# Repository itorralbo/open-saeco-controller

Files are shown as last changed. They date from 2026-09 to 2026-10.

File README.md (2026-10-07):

# Open Saeco Controller

Controladora open-source para sustituir la electrónica de la Saeco Incanto HD8911,
placa objetivo 421941308981/01. Proyecto independiente, sin afiliación a Philips/Saeco.

**Rev A: diseño en curso, sin hardware fabricado ni ensayado. Hay 230 VAC. Toda
etapa de potencia es experimental hasta verificación. El firmware actual no
controla cargas.**

## Objetivo
Controlar la máquina sin depender de la electrónica original, inicialmente por USB/web.
Conservar mecánica y cableado solo tras verificar compatibilidad. Se diseñará un frontal
nuevo que reproduzca la posición de los botones y use una pantalla reemplazable.
STM32 se ocupará del control; ESP32, de interfaz y comunicaciones.

## Documentación
- [Arquitectura](docs/architecture.md)
- [Reverse engineering HD8911](docs/HD8911/README.md)
- [Plan de caracterización de la cafetera](docs/HD8911/characterization-plan.md)
- [Mapa I/O preliminar](docs/io-map.md)
- [Diseño preliminar del frontal y pantalla](hardware/front-panel/README.md)
- [Subsistema display y UI (ST7789 + LVGL)](docs/display-ui.md)
- [Decisión de frontal/display (ADR-0001)](docs/adr/0001-front-panel-display-st7789.md)
- [Diseño de la principal](hardware/controller/core-design.md) y
  [su colocación y ruteo](hardware/controller/layout.md)
- [Arquitectura de potencia](hardware/power/power-architecture.md)
- [Abrir y editar los proyectos KiCad](hardware/kicad-workflow.md)
- [Componentes y fabricación JLCPCB](hardware/assembly/README.md)
- [Seguridad](docs/safety.md)
- [Roadmap y validación](docs/roadmap.md)
- [Licencias y fuentes](docs/licensing.md)

## Estructura
```
docs/                 arquitectura, seguridad, ingeniería inversa de la HD8911 y registro de verificación
hardware/controller/  principal completa: esquema, PCB de cuatro capas ruteada, BOM; no fabricable
hardware/front-panel/ frontal: esquema, PCB ruteada y paquete JLCPCB candidato, sin pedir
hardware/assembly/    catálogo de componentes con códigos JLC y stock observado
hardware/power/       diseño de las etapas de red, 24 V, válvula y watchdog
firmware/stm32/       núcleo C portable, sin BSP ni pines
firmware/esp32/       proyecto mínimo ESP-IDF
firmware/common/      contrato de comunicaciones propuesto
recipes/              ejemplo de simulación no ejecutable
sim/                  modelo de las dos placas para el simulador del firmware
tools/                generadores, layout, ruteo y comprobaciones de las dos placas
tests/                pruebas de bloqueo del núcleo
```

## Verificación local
Con Python 3: `python tools/check_scaffold.py`.
Conexiones del frontal: `python tools/check_front_panel.py` (no sustituye ERC).
Núcleo y suministro: `python tools/check_controller_core.py` (no sustituye ERC/DRC).
ERC y netlist nativos, con KiCad 10: `python3 tools/validate_kicad.py`.
Geometría de la PCB principal (condensadores de entrada de los bucks), con el
Python de KiCad desde `tools/`: `check_controller_pcb.py --self-test`.
Coherencia firmware ↔ placas: `python tools/build_board_model.py --check`
([simulador](sim/README.md), [informe](sim/board-report.md)).
Con CMake >= 3.20 y compilador C:
```
cmake -S firmware/stm32 -B build/host
cmake --build build/host --config Debug
ctest --test-dir build/host -C Debug --output-on-failure
```
El build host no produce firmware STM32 flasheable. USB/web, drivers, protocolos y
calibraciones aún no están implementados. Todos los pinouts y niveles eléctricos
sin evidencia permanecen TBD.

El material original de esta base se publica bajo [MIT](LICENSE). Referencias y
materiales de terceros conservan sus derechos; no se redistribuyen en este paquete.

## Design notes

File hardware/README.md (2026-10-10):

# Hardware

- [Frontal](front-panel/README.md): botones, LED y conector de pantalla, con la
  mecánica recuperada de la placa original. PCB ruteada, DRC limpio y paquete
  JLCPCB candidato, pendiente de las comprobaciones previas al pedido.
- [Principal](controller/core-design.md): lógica, USB de servicio, sensores,
  cargas de 24 V y de red y fuente aislada en una sola placa de cuatro capas,
  ruteada y con DRC limpio. [Contrato con el frontal](controller/front-panel-interface.md).
- [Potencia](power/README.md): etapas de red, válvula y watchdog.
- [Selección para montaje JLCPCB](assembly/README.md) y
  [proyectos KiCad](kicad-workflow.md).

La principal no es fabricable: faltan la comprobación 1:1 de conectores y su
acoplamiento con los mazos, y la revisión independiente de aislamiento y
seguridad. Su paquete JLCPCB es candidato: no pedirlo hasta
cerrarlos.

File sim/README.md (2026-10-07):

# Simulador de la cafetera

Entorno para probar el firmware sin hardware, coherente con las dos PCBs: el
cableado del simulador no se escribe a mano, se genera a partir de los netlists
de KiCad, así que un error de diseño aparece como un fallo de simulación.

| Fase | Contenido | Estado |
|---|---|---|
| F0 | Modelo de las dos placas, contrato de firmware, comprobaciones y `board_pins.h` | Hecha |
| F1 | STM32 en host contra la placa virtual: HAL, modelos de componentes y planta | Hecha; planta con valores supuestos |
| F2 | ESP32 en host: ST7789 y TCA9534 virtuales, protocolo v0 | Hecha; LVGL queda para el puerto ESP-IDF |
| F3 | Panel web local: frontal, pantalla, gráficas, inyección de fallos, VCD | Hecha |
| F4 | Menús y puesta a punto: pruebas de cargas y medidas, cafetera visual en el panel | Hecha; tiempos y corrientes de la planta supuestos |
| F5 | Recetas y máquina de estados completa | Pendiente |

## Entorno (macOS, Windows y Linux)

Hace falta Python 3.10 o posterior (CI usa 3.12). El código del simulador solo
usa la biblioteca estándar; lo único externo es un compilador de C para los dos
firmwares, y [`requirements.txt`](requirements.txt) lo trae con pip (`zig cc`,
paquete `ziglang`): no hacen falta Xcode, MinGW ni Visual Studio.

macOS / Linux:
```
python3 sim/setup_env.py
source .venv/bin/activate
```

Windows (PowerShell):
```
py sim\setup_env.py
.venv\Scripts\Activate.ps1
```

Si PowerShell no deja ejecutar `Activate.ps1`, basta con llamar a
`.venv\Scripts\python` en lugar de `python`.

[`setup_env.py`](setup_env.py) crea `.venv` en la raíz del repositorio, instala
los requisitos, copia [`.env.example`](.env.example) a `sim/.env` si no existe
y compila los dos firmwares para comprobar la cadena. Con el entorno activado,
los comandos de abajo funcionan igual en los tres sistemas.

`sim/.env` (ignorado por git) guarda lo propio de cada máquina, por ejemplo
otro compilador (`CC`) o el SDK de macOS (`SDKROOT`) para un compilador del
sistema; las variables ya definidas en la terminal mandan. Sin `CC`, el
simulador usa `zig cc` si está instalado y si no `cc`, `gcc` o `clang`. CI
pasa los escenarios en Windows y macOS con este entorno, y en Linux con el
`cc` del sistema.

## F0: modelo de placa

```
python tools/build_board_model.py           # regenera las salidas
python tools/build_board_model.py --check   # falla con errores de diseño o salidas viejas
python tools/build_board_model.py --as-if-fixed
python -m unittest discover -s tests/sim
```

`--as-if-fixed` repite las comprobaciones como si cada símbolo siguiera ya su
pinout de referencia: muestra lo que seguiría mal tras corregir los símbolos.
Los netlists se leen de `hardware/*/validation/netlist.xml`; tras editar un
esquema hay que regenerarlos con `tools/validate_kicad.py`.

Entradas:
- [Contrato de firmware](../firmware/common/signals.json): cada señal que usa el
  firmware (red, función, nivel activo, nivel en reset, a qué conector debe
  llegar y si va enclavada por el watchdog), el mazo entre placas, los rails y
  el teclado.
- [Pinouts de referencia](reference/pinouts.json) de cada CI activo, transcritos
  del fabricante con la fuente anotada.
- [Capacidades de los MCU](reference/mcus.json): funciones alternativas, canales
  ADC, pines reservados y estado tras reset. Un pin sin fila falla hasta que se
  añade desde la fuente.
- [Límites eléctricos](reference/devices.json) de cada CI y transistor (F1),
  con la hoja de datos de cada uno: VIH/VIL, VOH, VGS a la que se especifica
  RDS(on), IFT del opto, tensión de cierre del relé y tiempos del TPS3828.

Salidas (generadas, no editar):
- [Informe](board-report.md) con hallazgos, tabla de señales y entradas analógicas.
- `board-model.json`: componentes, redes globales y señales resueltas; es la
  entrada del simulador de F1.
- `firmware/stm32/include/board_pins.h` y `firmware/esp32/main/board_pins.h`:
  puerto, pin, AF y canal ADC de cada señal según los pads físicos.

## Qué comprueba

| Regla | Qué detecta |
|---|---|
| `symbol-pinout` | Símbolo cuyos pads no coinciden con el pinout del fabricante |
| `supply-pad`, `ground-pad`, `output-on-rail` | Alimentación o masa del CI real en una red de señal, o una salida unida a un rail |
| `pin-shift`, `signal-pad` | Señal que en el componente real cae en otro pin o en un pad de alimentación |
| `pin-caps`, `reserved-pin`, `strapping-pin` | Pin sin el periférico pedido (AF, ADC, USB) o reservado (SWD, BOOT0, flash/PSRAM) |
| `signal-path` | Orden que no llega a su carga o entrada que no viene de su conector, atravesando resistencias, puertas, drivers, optos, triacs, relé y mazo |
| `interlock` | Orden de carga que no pasa por una AND con `STM_NRST` (watchdog) |
| `reset-level` | Nivel de cada orden con el MCU en reset (pines en alta impedancia, pull internos de depuración) |
| `pull` | Entrada sin el pull-up o pull-down que requiere |
| `analog` | Divisores, NTC (ventana y °C/LSB) y límite de corriente del DRV8876 resueltos por análisis nodal |
| `harness` | Pines del mazo J104 ↔ J1 con redes distintas a cada lado |
| `keypad` | Dirección I²C del TCA9534, bus, mapa bit → tecla y LED |
| `uart-pair`, `unclaimed-net`, `power-domain` | TX con RX, redes del MCU que el firmware no usa, pull-ups en otro dominio |
| `drive` | Orden que no mueve su carga en el peor caso: activa, inactiva, con el MCU en reset y, si va enclavada, con `STM_NRST` bajo y el pin aún activo, con los rails al mínimo y al máximo |
| `drive-current` | Salida del MCU o de una puerta que entrega más corriente de la que garantiza su VOH/VOL |
| `drive-limit` | IF del opto, tensión de bobina o VDS por encima del máximo |
| `slow-edge` | Entrada lógica sin histéresis en una red RC más lenta que su Δt/Δv máximo |
| `back-feed` | Entrada de alimentación externa que llega al nodo de conmutación de un buck por bobinas o fusibles, sin cruzar otro rail |
| `reverse-polarity` | Entrada de banco cableada a mano (`external_supplies.unkeyed`) que, con el cable invertido, llega por fusibles o bobinas a algo distinto de un diodo serie, un TVS a masa, resistencias, condensadores no polarizados, una bobina de relé o conectores |
| `probe-header` | Cabecera de medida (`probe_headers`) con dos tensiones distintas en pines contiguos o un pin de raíl sin resistencia serie de al menos `min_ohms` |
| `offboard-supply` | Alimentación que sale de la placa por un mazo (`offboard_supplies`) sin un interruptor con límite de corriente ni una resistencia serie de al menos `min_ohms` |
| `tvs` | TVS que conduciría con el rail en su máximo (VWM) o que no empieza a conducir (VBR máx.) antes del máximo absoluto de lo que protege |
| `resistor-power` | Resistencia que disipa más de su potencia nominal (catálogo o tamaño de huella) en el peor estado; aviso por encima del 60 % |
| `wdi-reset` | Supervisor que enclava RESET ante un pulso en WDI (TPS382x sin A) cuyo WDI cambia, con RESET activo, según PB4 esté en alto, en bajo o liberado |
| `pin-voltage` | Pin de un MCU por encima de su máximo absoluto en algún estado, con los rails y VBUS al máximo |
| `input-level` | Entrada digital activa a cero que, con su contacto cerrado (50 Ω) o abierto, no pasa de VIL o VIH en las dos esquinas |

El modelo usa los pads físicos: cuando un símbolo no sigue su pinout de
referencia, el modelo se comporta como la placa que se fabricaría, no como el
dibujo. Representa el flujo de control y la red en continua por conmutación, no
transitorios, la red de 230 V más allá de quién tiene fase, ni la PWM más allá de
su nivel; no sustituye a ERC, DRC, ni a ensayos de integridad de señal, EMI o
aislamiento.

Las [pruebas de mutación](../tests/sim/test_board_model.py) parten de los
netlists con los símbolos corregidos, rompen una cosa cada vez y exigen que la
regla correspondiente la detecte.

## F1: placa virtual y firmware en host

```
python -m unittest discover -s tests/sim    # F0, F1 y escenarios del firmware
```

- [`circuit.py`](osc_sim/circuit.py): modelo DC por conmutación de las dos
  placas sacado de los netlists. Resistencias, salidas como fuentes de Thevenin,
  LED como caída directa, canales MOSFET como RDS(on), relé por la tensión de
  bobina y triacs por el opto que los dispara. Solo se fía de los puntos que
  garantiza el fabricante; entre ellos el dispositivo queda indefinido y todo lo
  que alimenta también. Cada punto se resuelve dos veces (indefinidos abiertos y
  cerrados) y solo es definido si ambas coinciden.
- [`drive.py`](osc_sim/drive.py): la regla `drive` y la tabla de márgenes del
  [informe](board-report.md). Las esquinas de los rails y las cargas de prueba
  están en el contrato (`rail_range`, `loads`, `drive` de cada orden).
- [`firmware.py`](osc_sim/firmware.py): compila `firmware/stm32` (controlador,
  BSP y bucle principal) con [`hal/hal_sim.c`](hal/hal_sim.c) como biblioteca y
  la carga con ctypes. Usa `$CC` (por defecto `cc`) y `$SDKROOT` si está
  definido; en macOS con las Command Line Tools rotas, el `clang` de Xcode.
- [`board.py`](osc_sim/board.py): pasos de 1 ms. Los pines que el firmware
  configura pasan a la red, U601 vigila WDI y gobierna `STM_NRST`, el STM32 se
  resetea y arranca según ese nivel, y los niveles, códigos ADC y flancos vuelven
  al firmware. Tras el reset los pines están en analógico y UCPD1 deja su Rd de
  5,1 kΩ en PB4/PB6 hasta que el BSP lo quita. U601 usa el extremo de cada rango
  que pone a prueba el caso: time-out de 0,9 s para el firmware sano, 2,5 s para
  el colgado, y 300 ms de reset al arrancar.
- [`plant.py`](osc_sim/plant.py): caldera y NTC, bomba y caudalímetro, grupo con
  sus micros, puerta, válvula y sensor de agua en los pines de los conectores.
  Los valores medidos llevan su fuente; los marcados *ASSUMED* (masa térmica,
  caudal, recorrido del grupo, salida de JP22) esperan a la caracterización.

Los [escenarios](../tests/sim/test_f1.py) comprueban el arranque en las dos
esquinas, que el firmware mantiene callado el watchdog, que un núcleo colgado se
resetea, que el interlock corta las órdenes de un núcleo desbocado en el mismo
paso en que U601 baja `STM_NRST`, que olvidar el *dead battery* de UCPD deja
`nFAULT` indefinido, y la caldera/NTC, el grupo/IPROPI y los flancos del
caudalímetro.

## F2: interfaz, frontal y protocolo

- [`firmware.py`](osc_sim/firmware.py) compila también el núcleo del ESP32
  (`firmware/esp32/core`) con [`hal/hal_esp_sim.c`](hal/hal_esp_sim.c). Sus
  pines entran en el circuito como los del STM32; el I²C y el SPI se resuelven
  al momento en Python.
- [`front.py`](osc_sim/front.py): TCA9534 y ST7789V al otro lado del mazo. Solo
  responden con `3V3_UI` presente; el TCA9534 lee cada tecla como la tensión en
  su pin (pulsador, pull-up y serie del netlist), su INT es una bajada en drenador
  abierto sobre el circuito, y la pantalla descodifica CASET/RASET/RAMWR sobre un
  framebuffer de 320 × 240.
- [`board.py`](osc_sim/board.py) lleva los bytes de la UART entre los dos
  firmwares a 115200 baudios, solo con los dos pines configurados y la línea en
  reposo alto en el receptor, y registra `backfeed` si el ESP32 deja en alto una
  línea del frontal con `3V3_UI` apagado.

Los [escenarios](../tests/sim/test_f2.py): arranque y enlace en las dos
esquinas, STATUS con los rails reales, núcleo FAULT si el ESP32 se cuelga,
pantalla de enlace perdido y recuperación si se cuelga el STM32, START rechazado
como respuesta normal, tecla mantenida al arrancar, rebotes, puerta abierta y
CLEAR_FAULT, standby con el LED, teclado colgado recuperado con un ciclo de
`3V3_UI` sin backfeed, y que el detector de backfeed salta con una línea en alto.

## F3: panel web local

```
python tools/sim_panel.py              # http://127.0.0.1:8765/
python tools/sim_panel.py --speed 5 --corner min
```

[`panel.py`](osc_sim/panel.py) ejecuta los dos firmwares en la placa virtual en
tiempo real (o más rápido) y sirve [`panel/index.html`](panel/index.html), sin
dependencias externas y solo en 127.0.0.1:

- Frontal con las siete teclas en su sitio (mantener pulsado = pulsada), el LED
  STBY y la pantalla tal como la pinta el ST7789V virtual.
- Estado del STM32 y del ESP32, enlace, peticiones y respuestas, `3V3_UI`,
  STATUS, cargas, planta y registro de eventos (watchdog, resets, backfeed).
- Gráficas de caldera, rails y grupo.
- Inyección: puerta, grupo, NTC abierto, nFAULT del DRV8876, STM32, ESP32 o
  teclado colgados, ruido en la UART, rails en sus esquinas, nivel del depósito,
  café en la tolva y sensor de agua (forzado o según el depósito);
  pausa, paso de 100 ms, reinicio y velocidad.
- [VCD](osc_sim/vcd.py) de las señales digitales (órdenes del STM32,
  `STM_NRST`, WDI, enlaces, cargas, teclas, estado del núcleo y pantalla), para
  GTKWave, PulseView o Surfer.

API: `GET /api/state`, `/api/history`, `/api/frame` (RGB565 de 320 × 240),
`/api/vcd`; `POST /api/cmd` con `{"cmd": ...}`. Los
[escenarios](../tests/sim/test_f3.py) la recorren en un puerto efímero.

## F4: menús y puesta a punto

- El ESP32 pinta menús de texto ([`ui.c`](../firmware/esp32/core/ui.c)) y el
  STM32 ejecuta las pruebas de [`service.c`](../firmware/stm32/src/service.c)
  ([protocolo](../firmware/common/protocol.md#pruebas-de-puesta-a-punto)).
- La [planta](osc_sim/plant.py) añade depósito (la bomba se queda sin caudal
  vacío y el sensor JP22 sigue el nivel), tolva y molinillo, el estado de cada
  carga y un arranque del motor con constante de tiempo, que da el pico de
  arranque que mide la prueba del grupo.
- El panel dibuja la cafetera: depósito, bomba, caudalímetro, caldera con el
  calentador y el NTC, válvula, tolva y molinillo, grupo con su posición,
  sentido y corriente, puerta, K701 y los tres triacs. Junto a cada carga, dos
  pilotos: la orden del pin del STM32 y la carga realmente alimentada según el
  netlist; una orden sin carga sale discontinua y una carga sin orden, en rojo.
  El informe de la prueba en curso aparece con sus unidades, y el texto de la
  pantalla también como texto.

Qué mide cada prueba y qué no: la placa mide los rails, la corriente del grupo
(IPROPI), la del molinillo (U704), el NTC, el caudalímetro y los finales de
carrera; las corrientes del calentador, la bomba y la válvula necesitan una
pinza en la sesión de [caracterización](../docs/HD8911/characterization-plan.md),
y las pruebas solo fijan el tiempo y la ventana.

Corriente del molinillo (2026-10-06): U704 entra en el modelo de placa como
dispositivo `hall_current` (su entrada es un conductor de 0,7 mΩ en la línea +
de JP8, su salida VS/2 + 100 mV/A) y la comprobación analógica `hall` exige que
JP8 esté en serie con él y que el rango quepa en el ADC. La planta da la
corriente rectificada de 100 Hz del motor: arranque como rotor bloqueado,
marcha con grano, en vacío y bloqueo (valores supuestos), y una cámara que
recibe el molido y que el grupo vacía al volver a reposo; la corriente al
prensar crece con los gramos. El panel la dibuja junto al molinillo, con dos
fallos nuevos: muelas atascadas y conducto tapado.

Los [escenarios](../tests/sim/test_f4.py) recorren los menús y cada prueba
contra la planta: entradas, ciclo del grupo con I0 en 100-300 mA, válvula,
relé y molinillo sin tocar otras cargas, bomba con calibración del
caudalímetro, bomba sin agua (sin caudal), calentador hasta 90 °C con la
sobreoscilación; molinillo con su corriente, tolva que se vacía a mitad,
sin grano desde el principio y muelas bloqueadas; dosis prensada y conducto
tapado; y que se rechazan con la puerta abierta y se abortan con STOP, con
volver, al abrir la puerta y si se cuelga el ESP32, con todas las cargas a
cero.

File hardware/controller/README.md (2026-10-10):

# Controladora principal

[Diseño de la principal en KiCad](core-design.md): STM32G431RBT6 y
ESP32-S3-WROOM-1U-N8R8 con antena externa U.FL, reset, depuración, UART y USB-C
de servicio. La fuente Mean Well IRM-30-24 va en la propia placa; de sus 24 V
salen el buck de 12 V y, tras él, el de 3,3 V y el corte del frontal. Incluye el
acondicionamiento de NTC, caudalímetro, nivel de agua y tres contactos; un
DRV8876 para el motor del grupo y una etapa low-side para la válvula, cada uno
con su fusible; y las etapas de triac de calentador, bomba y molinillo detrás de
un relé general K701. Un TPS3828 supervisa el STM32 y las puertas AND U602–U604
anulan todas las órdenes de carga y el armado del relé mientras hay reset.

223 posiciones: 214 con MPN y código LCSC, de ellas R415 y R416 sin montar
(DNP); C705, R727, C706 y R728, snubbers RC de los triacs, y C708, supresión del
molinillo, sin montar y sin pieza; J115 y J117 (LEOCO, que JLCPCB no tiene) con MPN y sin código; J111 y
J121, puentes de soldadura. Los tres fusibles de red son Littelfuse 215 de
1500 A a 250 VAC (F702, de 2 A, en pinzas 01110501Z; F701, de 12 A, soldado). J105, J106 y J113 (JP13, JP5 y JP3)
son HR A2506WV, JP8 y JP24 LEOCO 3941P03*000 y 5001P020013, JP17 y JP19 TE RAST 5
1971845-3 y -4 y JP1/JP9 lengüetas TE 63824-1, todas identificadas por el
propietario o casadas con sus fotos. Desde el 2026-10-10 también J107 y J108
(JP14 y JP16, HR A2506WV-02P y -08P) y J109 (JP22, JST ZH B3B-ZR).

La PCB es de cuatro capas, JLC04161H-7628, con planos de GND y 3,3 V solo en el
lado SELV, y está [colocada y ruteada](layout.md) en las posiciones de la placa
original: DRC con todas las severidades sin infracciones ni conexiones abiertas.
La barrera red/SELV de 8 mm es una regla del DRC. Detalle del proyecto en
[kicad-workflow.md](../kicad-workflow.md); reglas y apilado en
[manufacturing.md](manufacturing.md), con el [paquete JLCPCB candidato](fabrication/)
(Gerbers, BOM y CPL, sin pedir); arquitectura de potencia en
[power-architecture.md](../power/power-architecture.md); suministro en
[assembly](../assembly/README.md).

El [contrato del frontal](front-panel-interface.md) fija J104 y los GPIO del
ESP32 para pantalla, botones, UART y USB. Dos divisores permiten leer por ADC los
rails de 12 V y 24 V, y J114 permite medirlos en banco, cada raíl entre dos masas y tras 10 kΩ.

**No es fabricable.** Falta comprobar la placa impresa 1:1 contra la original y
los mazos y el acoplamiento de sus cabeceras, medir la emisión conducida,
medir las cargas y pasar una revisión independiente de aislamiento. Nada está
ensayado. No trasladar pines de una placa de desarrollo al arnés sin verificación.

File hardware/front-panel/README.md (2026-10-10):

# Frontal Rev A.0

Decisión del propietario, 2026-09-16: reproducir la PCB frontal para conservar
la disposición de botones y montar una pantalla nueva compatible con el hueco.
Se conserva como objetivo la geometría original. El 2026-09-18 se recuperaron por
fotogrametría contorno, taladros y centros de los siete pulsadores (184 × 54,3 mm);
están aceptadas como línea base del layout y aplicadas a la PCB de trabajo. Ver
[registro mecánico](mechanical.md).

Estado del layout (2026-09-18): **PCB colocada y ruteada, DRC limpio y paquete JLCPCB
candidato**, pendiente de revisión antes de pedir. Ver [layout](layout.md).

## Entregables de esta iteración

- [Esquema KiCad](kicad/front-panel-reva.kicad_sch), con símbolos embebidos.
- [Proyecto KiCad](kicad/front-panel-reva.kicad_pro) y
  [PCB](kicad/front-panel-reva.kicad_pcb) colocada y ruteada, con huella propia de
  los pulsadores en [OpenSaeco.pretty](kicad/OpenSaeco.pretty/).
- [Layout, mapa de teclas y registros del TCA9534](layout.md);
  vistas [superior](preview/pcb-top.png) e [inferior](preview/pcb-bottom.png).
- [Paquete JLCPCB candidato](fabrication/): Gerber y taladros, BOM y CPL.
- [Vista nativa de KiCad](validation/front-panel-reva.svg) y
  [validación y límites](../kicad-workflow.md).
- [Vista SVG del circuito](preview/front-panel.svg), generada como ayuda de revisión.
- [BOM candidata](bom-draft.csv) y [conexiones previstas](design-nets.json).
- [Contrato con la principal](../controller/front-panel-interface.md).
- [Registro mecánico fotogramétrico](mechanical.md), [datos](mechanical-source.json)
  y [plano 1:1 imprimible](validation/mechanical-1to1.svg).
- [Selección de componentes y montaje JLCPCB](../assembly/README.md): 42 de 42
  posiciones con MPN y código JLC; J1 (Würth WR-MM) sin stock en JLCPCB el
  2026-10-08, se compra aparte y se suelda a mano.

El circuito contiene alimentación externa de 3,3 V, un TCA9534PWR, siete canales
de pulsador filtrados (los siete de la PCB original), el LED de standby en el octavo
puerto y una salida a adaptador de display SPI. ERC y DRC nativos limpios. No está
pedido: faltan las comprobaciones de [layout.md](layout.md#pendiente-antes-de-pedir).

## Circuito propuesto

El ESP32 permanece en la controladora principal. Lee botones por I²C y escribe
la pantalla por SPI. El STM32 recibe solicitudes a través del protocolo del
proyecto y conserva la autoridad sobre las cargas.

U1 es un **TCA9534PWR, TSSOP-16**. A0/A1/A2 van a masa, dirección de siete bits
`0x20`. Sus ocho puertos arrancan como entradas; P0–P6 leen teclas y P7 se configura
como salida para el LED (ver [layout.md](layout.md#teclas-led-y-registros-del-tca9534)).
INT es una salida activa a nivel
bajo de drenador abierto. Ver pinout y registros en la
[hoja de datos TI SCPS197D](https://www.ti.com/lit/ds/symlink/tca9534.pdf),
§5, §8.5 y §8.6. El esquema y la BOM se refieren al TCA9534, no al TCA9534A.

Cada canal de tecla tiene 10 kΩ a 3,3 V, 100 nF a masa y un pulsador normalmente abierto
a masa a través de 1 kΩ. La resistencia serie limita la corriente si un error
configura el puerto como salida alta. Estimación nominal: 0,30 V pulsado,
0,30 mA por pulsador y constante de subida de 1 ms. El RC reduce ruido;
el antirrebote temporal sigue siendo necesario.

R1/R2 = 4,7 kΩ son las únicas pull-ups I²C previstas. R3 = 10 kΩ polariza INT.
C1 = 100 nF y C2 = 1 µF quedan junto a U1; C3 = 10 µF, junto al pin 1 de J1.
Las huellas 0603 tienen referencias de compra candidatas en la BOM; falta comprobar
capacitancia efectiva, temperatura, corriente y espacio. Se usan X7R para 100 nF
y X5R para 1 µF/10 µF según el catálogo de montaje consultado. Pulsadores: HRO
K2-1102SP-A4SC-04 (JLC C83916), 6 × 6 × 4,3 mm como el original medido.
LED STBY: KT-0603R rojo (C2286) con R7 = 470 Ω a 3,3 V, activo con P7 a 0.

J2 lleva alimentación, masa, MOSI, reloj, CS, DC, RESET y BL. CS y RESET
tienen pull-up; BL tiene pull-down para solicitar retroiluminación apagada al
arranque. **BL es una señal lógica**, prevista para un módulo con driver de LED.
No alimentar directamente una retroiluminación desde ese GPIO. J2 es un JST PH de
8 vías vertical (B8B-PH-K-S, JLC C157974) con el orden del cable PH del módulo
Waveshare 2" (VCC GND DIN CLK CS DC RST BL), útil para el banco. El adaptador
definitivo deberá respetar ese orden y añadir driver si lo necesita la pantalla.

J1 es el Würth WR-MM 690367181672 que el propietario identificó el 2026-10-01 en
el JP3 original, igual que J104 de la principal: 16 contactos a 1,27 mm al
tresbolillo. El cable original es plano, de 16 hilos y 1:1; su pestillo entra en
un taladro de 1,5 mm junto al pin 1, que lo retiene y fija el sentido. Va sobre la
zona del JP3 original, en su pestaña, cara de componentes. JLCPCB lo lista como C19103863 sin stock (2026-10-01).

## Pantalla reemplazable

> Decisión registrada (2026-09-18): se adopta un **TFT ST7789 2,0"** (240×320, SPI 4 hilos, 3,3 V) sobre frontal nuevo; se descarta reutilizar la PCB OEM. Ver [ADR-0001](../../docs/adr/0001-front-panel-display-st7789.md) y el [subsistema display + UI](../../docs/display-ui.md) (stack LVGL 9 + esp_lcd, SPI 10 MHz, presupuestos y árbol de pantallas). La tabla siguiente se conserva como registro de evaluación de hueco.

La compatibilidad se define por ventana visible, contorno total, altura,
orientación, lógica de 3,3 V, consumo y protocolo. La diagonal sola no basta.
La PCB de botones y el adaptador del display serán diseños independientes,
para cambiar de pantalla sin recolocar los pulsadores.

Referencias para comparar dimensiones, **sin selección ni compra todavía**:

| Módulo candidato | Controlador / resolución | Área visible (mm) | PCB del módulo (mm) |
|---|---|---|---|
| Waveshare 2 inch LCD Module | ST7789VW / 240 × 320 | 30,60 × 40,80 | 58,0 × 35,0 |
| Waveshare 2.4 inch LCD Module | ILI9341 / 240 × 320 | 36,72 × 48,96 | 70,50 × 43,30 |

Fuentes del fabricante consultadas el 2026-09-16:
[módulo 2 pulgadas](https://www.waveshare.com/product/displays/lcd-oled/2inch-lcd-module.htm)
y [módulo 2,4 pulgadas](https://www.waveshare.com/product/2.4inch-lcd-module.htm).
Para el segundo, el fabricante vincula el nivel lógico a la alimentación:
se evaluará alimentado a 3,3 V, no a 5 V.

Estos módulos sirven para evaluar el hueco y prototipar. El diseño final puede
necesitar un panel sin carrier comercial. J2 no incorpora MISO ni táctil:
un display que necesite lectura, touch o interfaz RGB/paralela requiere revisar
el adaptador y las señales disponibles, no solo cambiar el controlador software.

## Comportamiento de firmware previsto

1. Mantener BL bajo y CS alto durante la inicialización. Aplicar el reset y los
   tiempos del display finalmente seleccionado antes de habilitar la imagen.
2. Configurar U1 en este orden: Output (`0x01`) = `0xFF` (LED apagado), Polarity
   (`0x02`) = `0x00`, Configuration (`0x03`) = `0x7F`; leer Input (`0x00`) con los
   bits 0–6. P7 (bit 7 de Output) solo controla el LED, activo a 0.
3. Leer cada 5 ms como punto de partida y exigir 20 ms de estabilidad.
   INT permite adelantar una lectura; conservar el sondeo para detectar fallos.
   Son objetivos iniciales de firmware, aún no implementados ni ensayados.
4. Tras arranque/reconexión, esperar liberación de todos los botones antes de
   aceptar una pulsación. No convertir una tecla mantenida en START al reiniciar.
5. NACK, lectura caducada o fallo del bus invalidan el teclado: no equivalen a
   «ningún botón pulsado». El frontal no podrá generar nuevas solicitudes START.
   La política del ciclo en curso corresponde al STM32 y queda por definir.

U1 no dispone de reset externo: recuperar I²C y reescribir configuración puede
no bastar tras ciertos fallos de alimentación. La principal incorpora un corte
TPS2553 con límite de corriente para `3V3_UI`; quedan por ensayar la secuencia de apagado y la prevención
de alimentación parásita por GPIO con el display y el arnés definitivos.

## Comprobación y edición

`python3 tools/generate_front_panel.py` regenera esquema, SVG, BOM y conexiones.
El generador es la fuente inicial: no ejecutarlo sobre ediciones manuales de KiCad
sin incorporarlas primero. La vista SVG es una representación auxiliar, no una
exportación de KiCad ni evidencia de que su parser acepte el archivo.

`python3 tools/check_front_panel.py` comprueba las conexiones del archivo de
esquema contra requisitos del circuito. `python3 tools/validate_kicad.py` ejecuta
ERC y coteja la netlist nativa de KiCad contra los 42 componentes y 118 pines.
`python3 tools/render_front_panel_mechanics.py` regenera el plano 1:1 y
`python3 tools/apply_front_panel_mechanics.py` aplica contorno, taladros y
referencias a la PCB desde [mechanical-source.json](mechanical-source.json).
`tools/sync_front_panel_pcb.py` y `tools/layout_front_panel_pcb.py` (Python de KiCad)
llevan las huellas a la PCB, colocan y rutean con Freerouting; `python3
tools/export_front_panel_fab.py` genera el paquete JLCPCB. Detalle en [layout.md](layout.md).

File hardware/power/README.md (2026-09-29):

# Potencia experimental / no verificada

Ya se midieron 27,5 Ω en el calentador, 68 Ω en el molino, 56,7 Ω en la
electroválvula y 54,7 Ω en el motor del grupo. El grupo tiene un puente H
DRV8876 y la [electroválvula una etapa low-side](valve-driver.md) con el pinout
confirmado. La [etapa de red y cargas](mains-stage.md) (relé general, fusibles,
varistor y triacs de calentador, bomba y molinillo) está en el esquema y en la
PCB ruteada. Un [watchdog e interlock hardware](watchdog-interlock.md) anula
todas las órdenes de carga durante reset o timeout.

La [arquitectura de alimentación de Rev A](power-architecture.md) integra red,
bomba, calentador y molino en la misma PCB, físicamente fuera del dominio SELV,
y conserva entradas externas aisladas de 12 V y 24 V para el banco. Incluye el
presupuesto provisional y lo que queda por diseñar. Las fotos confirman que la
original usa una fuente flyback; Rev A sustituye ese primario a medida por un
módulo Mean Well IRM-30-24 encapsulado montado en la propia tarjeta.

Faltan corrientes dinámicas, arranque, aislamiento y modos de fallo de cada carga.
Un motor DC puede trabajar a tensión peligrosa. Fuente aislada y corte independiente
requieren revisión. No se autoriza fabricación.

JP8 y JP24 son las cabeceras LEOCO 3941P03*000 (3 vías a 3,96 mm) y
5001P020013 (2 vías a 5,00 mm), identificadas por el propietario el 2026-09-29;
JLCPCB no las tiene. JP17 es un TE RAST 5 1971845-3, identificado por el
propietario. Los tres están ya en el esquema y en la PCB, igual que JP19, el TE
RAST 5 1971845-4.

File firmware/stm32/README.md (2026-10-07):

# Núcleo STM32

C99 portable. CMake compila para host; no es firmware flasheable.
El esquema usa un STM32G431RBT6 y ya fija sus pines
([core-design.md](../../hardware/controller/core-design.md)); startup,
linker script y el puerto de `osc_hal.h` al micro (CubeMX/LL) siguen TBD.

- `controller.c`: máquina de estados. Ningún estado del controlador autoriza
  cargas; solo lo hace una prueba de puesta a punto.
- `service.c`: pruebas de puesta a punto ([protocolo](../common/protocol.md#pruebas-de-puesta-a-punto)).
  Solo mueven cargas con el núcleo en SAFE_IDLE y el enlace vivo; cada una
  tiene tiempo máximo, la puerta y nFAULT se vigilan en cada paso, y el bucle
  principal deja de escribir sus salidas en cuanto el núcleo sale de SAFE_IDLE.
  El molinillo se juzga por su corriente (U704) en bloques de 100 ms con
  `osc_grinder_verdict()`: falta de grano o bloqueo; la dosis, por la subida
  de la corriente del grupo al prensar con `osc_dose_present()`. Umbrales en
  `controller.h`, supuestos hasta caracterizar el motor.
- `osc_hal.h`: el poco acceso al hardware que necesita el BSP (modo y nivel de
  pin, ADC, contador de flancos, PWM, desactivar el *dead battery* de UCPD,
  UART, calibración de VREFINT, milisegundos). En host lo implementa
  `sim/hal/hal_sim.c`.
- `bsp.c`: las señales del [contrato](../common/signals.json) sobre los pines
  de `board_pins.h`, generado desde los netlists. Deja cada orden inactiva antes
  de convertir su pin en salida y quita el Rd de UCPD de PB4/PB6 antes de usarlos.
- `app.c`: bucle principal. Conmuta el impulso del watchdog cada 100 ms (U601
  resetea a los 0,9 s como pronto), atiende el [protocolo v0](../common/protocol.md)
  con el ESP32 (STATUS cada 100 ms, enlace perdido a los 350 ms, TEST y
  TEST_REPORT), lee entradas,
  ejecuta el controlador cada 10 ms y escribe las salidas. La corriente del
  molinillo se muestrea en cada vuelta (1 ms, `bsp_sample()`) y se promedia por
  tick: es una onda rectificada de 100 Hz que un muestreo cada 10 ms aliasaría. Tras el reset espera
  hasta 2 s en `OSC_BOOT` a que aparezca el ESP32; sin enlace pasa a `OSC_FAULT`,
  del que solo sale con CLEAR_FAULT. Los rails y la corriente se escalan con la
  VDDA medida contra VREFINT y su calibración de fábrica, no con 3,3 V supuestos.

El [simulador](../../sim/README.md) (F1, F2) ejecuta este código contra la placa
virtual. No usar este scaffolding como supervisor de seguridad.
`osc_heater_cycles_allowed()` fija ya la regla de reparto de la fase de cargas
(calentador a 3 de cada 5 ciclos mientras muele el molinillo); ver
[power-architecture.md](../../hardware/power/power-architecture.md#reparto-de-corriente-en-la-fase-de-cargas).
`osc_heatsink_step()` y `osc_heater_cycles_thermal()` añaden la limitación
térmica del calentador (issue #2). Con el aire de RT701 (PB14) y la potencia de
cada triac estiman la unión de Q703 y le quitan ciclos por encima de 105 °C,
hasta ninguno a 120 °C. El llamador toma el menor de los dos límites.
Constantes supuestas hasta TH-03.

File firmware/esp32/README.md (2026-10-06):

# ESP32: interfaz

Proyecto ESP-IDF mínimo, candidato ESP32-S3; `main/app_main.c` solo emite
diagnóstico. La lógica de la interfaz está en [`core/`](core), C99 portable sobre
[`esp_hal.h`](core/esp_hal.h), cuyo puerto a ESP-IDF (driver/gpio, i2c_master,
spi_master, uart, ledc) sigue TBD. En host la ejecuta el
[simulador](../../sim/README.md) (F2) contra la placa virtual.

- `frontpanel.c`: TCA9534 del frontal. Configura Output, Polarity y
  Configuration en ese orden, muestrea cada 5 ms o al bajar INT, antirrebote de
  20 ms, ignora una tecla mantenida desde el arranque hasta que se suelta y marca
  el teclado como inválido ante un NACK (no es "ninguna tecla").
- `display.c`: ST7789V por SPI a 10 MHz. Reset y despertar como máquina de
  estados no bloqueante, apaisado (MADCTL 0x60), RGB565 y retroiluminación solo
  sobre una imagen ya pintada. Pinta una pantalla de texto (título de color por
  estado, 12 líneas de 26 caracteres y pie) con la fuente 5×7 de `font5x7.c`
  (generada por [`tools/make_font5x7.py`](../../tools/make_font5x7.py)), y solo
  repinta lo que cambia; LVGL 9 con `esp_lcd` la sustituirá en el destino
  ([display + UI](../../docs/display-ui.md)).
- `ui.c`: menús, lógica pura (teclas dentro, una petición fuera, pantalla de
  texto). Inicio con estado, caldera, puerta, grupo y rails; MENU con café,
  puesta a punto, información y borrar fallo. Puesta a punto lista las pruebas
  de [`service_ids.h`](../common/service_ids.h): cada una explica qué hace y qué
  preparar, deja ajustar su parámetro (ml, °C o ms), y muestra en vivo paso,
  tiempo y valores. Tras la de bomba se introduce el volumen pesado y calcula
  los pulsos por litro del caudalímetro. La de molinillo muestra la corriente
  y para si falta grano o se atasca; la de dosis muele, prensa y dice si llegó
  café a la cámara.
- `esp_app.c`: enlace con el STM32 ([protocolo v0](../common/protocol.md)),
  STATUS y TEST_REPORT, teclas hacia `ui.c` y su pantalla hacia `display.c`.
  Si el teclado no responde durante 1 s pide al STM32 apagar y encender el
  frontal (UI_POWER), con todas sus líneas en alta impedancia mientras está
  apagado.

Mapa de teclas provisional, hasta cerrar la UX ([`ui.h`](core/ui.h)): columna
izquierda SW1 ▲, SW2 ▼, SW3 volver; derecha SW7 STOP, SW6 MENU, SW5 OK; SW4 (la
de STBY) standby con el LED. En inicio, OK pide café (que el núcleo aún rechaza)
o borra el fallo. STOP para cualquier prueba desde cualquier página.

En consola con ESP-IDF instalado y activado:
```
cd firmware/esp32
idf.py set-target esp32s3
idf.py build
```
Versión SDK validada: TBD. Registrar versión y placa en el primer build verificado.

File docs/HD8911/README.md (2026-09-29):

# Reverse engineering HD8911

## Evidencias iniciales
- E001: identificación aportada por propietario: HD8911, 421941308981/01, 220–230 V.
- E002: `docs/HD8911/Service_manual_-_HD8911_01_-_2016-05-16.pdf`, referencia
  local de terceros no incluida en Git. Páginas PDF 34–37 del capítulo 05 y página
  PDF 59, capítulo 10, consultadas y cotejadas visualmente.
  Cubre variantes: cotejar con la unidad concreta.
- E003: `docs/HD8911/Exploded view Saeco Incanto.pdf`; tablas de cargas, sensores,
  arneses y referencias cotejadas con la variante HD8911.
- E004: fotografías HEIC en `docs/HD8911/photos/` y adjuntos del propietario.
  HEIC inventariados; observaciones sobre JPEG de la conversación en [photos.md](photos.md).
- E005: conversación previa. Las inferencias del asistente no son evidencia medida.
- E006: transcripción aportada por el propietario del capítulo 10, contrastada con
  la página PDF 59 y consolidada en [electrical-diagram.md](electrical-diagram.md).
- E007: referencias de cargas y sensores identificadas por el propietario,
  contrastadas con manual, despiece y hojas de fabricante en
  [components.md](components.md).

El manual y las referencias confirman conectores, destinos y buena parte de las
tensiones y potencias. JP5 y los colores funcionales de JP22 ya están identificados;
siguen pendientes la forma de salida del sensor capacitivo, los contactos de JP16
y corrientes dinámicas de motores. Ya hay
resistencias de cuatro cargas y continuidad funcional de JP14, y el propietario
identificó las cabeceras de JP3, JP5, JP8, JP13, JP17, JP19 y JP24. No se han importado esquemas internos, firmware
ni conclusiones eléctricas no mostradas por el fabricante. Los archivos fuente no
se incluyen en este paquete y conservan sus derechos originales.

## Procedimiento inicial
1. Confirmar variante, revisión, etiquetas y orientación de cada conector por fotografía.
2. Inventariar cavidades, cables y destinos físicos con máquina desconectada y ausencia
   de tensión verificada; energía almacenada tratada por personal cualificado.
3. Registrar continuidad y dominios de aislamiento sin inferirlos por aspecto.
4. Leer marcajes de cargas; separar catálogo, hipótesis y resultados medidos.
5. Definir ensayos apropiados para sensores, caudal, motor y calibraciones.
6. Revisar el mapa antes de elegir fuentes, drivers y pines MCU.

Las comprobaciones físicas que desbloquean el siguiente esquema están preparadas
en el [registro y paquete de medidas](measurements.md). Los ensayos iniciales
para caracterizar la cafetera en marcha, con la placa original y con el primer
prototipo, están en el [plan de caracterización](characterization-plan.md).

Ensayos de red requieren procedimiento separado revisado y personal cualificado.
Este documento no proporciona instrucciones de trabajo bajo tensión.

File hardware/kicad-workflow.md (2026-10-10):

# Proyectos KiCad — estado y edición

Los dos proyectos se han cargado con KiCad CLI 10.0.6. Para abrirlos en el gestor:

- [Principal](controller/kicad/controller-core-reva.kicad_pro),
  [esquema](controller/kicad/controller-core-reva.kicad_sch),
  [PCB de trabajo](controller/kicad/controller-core-reva.kicad_pcb).
- [Frontal](front-panel/kicad/front-panel-reva.kicad_pro),
  [esquema](front-panel/kicad/front-panel-reva.kicad_sch),
  [PCB de trabajo](front-panel/kicad/front-panel-reva.kicad_pcb).

Cada carpeta incluye `OpenSaeco.kicad_sym`, `sym-lib-table` y `fp-lib-table`.
Los símbolos son locales al proyecto. Las huellas vienen de las bibliotecas
estándar de KiCad 10, mediante `KICAD10_FOOTPRINT_DIR`, o de la biblioteca local
`OpenSaeco.pretty` de cada proyecto (conectores identificados, fuente, relé,
optos con ranura, fusible del molinillo, USB-C vertical y pulsadores). No dependen
de una ruta absoluta del equipo de desarrollo.

## Qué contienen las PCB

Las huellas y sus redes vienen de la netlist **nativa** de KiCad, con los UUID de
los símbolos para poder actualizar desde el esquema, y con fabricante, MPN y
código JLC como campos ocultos. Los scripts guardan cada PCB y la vuelven a
cargar con `pcbnew`, cotejando cada pad y su red.

| Proyecto | Componentes en esquema | Huellas en PCB | Sin huella |
|---|---:|---:|---|
| Principal | 187 | 187 (más MH1–MH3) | — |
| Frontal | 42 | 42 | — |

- **Principal**: [colocada y ruteada](controller/layout.md) sobre el
  [contorno y los tres taladros aceptados](../docs/HD8911/main-board-mechanics.md),
  con los conectores de mazo en sus posiciones originales. Cuatro capas, todas
  las redes conectadas, rellenos de masa en el lado SELV y serigrafía. **No es
  fabricable**: no generar Gerbers, BOM de fabricación ni CPL hasta la
  comprobación 1:1, la identificación de JP14/JP16/JP22 y la revisión de
  aislamiento.
- **Frontal**: [colocado y ruteado](front-panel/layout.md) sobre el
  [contorno aceptado](front-panel/mechanical.md), con paquete JLCPCB candidato
  pendiente de las [comprobaciones previas al pedido](front-panel/layout.md#pendiente-antes-de-pedir).

## Validación

ERC nativo: cero errores y cero avisos en ambos esquemas, sin excluir
infracciones. Se mantiene la configuración estándar de KiCad; los cuatro
controles opcionales desactivados por defecto figuran en cada informe. Los
PWR_FLAG declaran las fuentes aisladas de J101/J112 y los nodos de potencia
separados por elementos pasivos; en el frontal, J1 declara su alimentación
externa. Los tipos de pin genéricos de los GPIO no comprueban la configuración
del firmware.

La netlist XML de KiCad coincide con los 612 pines de la principal y los 118 del
frontal.

| Resultado del DRC (todas las severidades) | Principal | Frontal |
|---|---:|---:|
| Infracciones geométricas/de reglas | 0 | 0 |
| Conexiones pendientes de rutear | 0 | 0 |
| Huellas ausentes respecto al esquema | 0 | 0 |
| Diferencias adicionales de paridad | 3 taladros mecánicos intencionales | 0 |

Las reglas de la principal (`controller-core-reva.kicad_dru`, escritas por
`configure_controller_rules.py`) incluyen la barrera de 8 mm de separación y
creepage entre red y SELV, 2,5 mm entre redes de red distintas y las
excepciones por pieza de optos y triacs; ver [manufacturing.md](controller/manufacturing.md).
El pad expuesto del ESP32 usa doce vías térmicas de 0,20 mm, el mínimo de taladro
del proyecto y el preferido por JLCPCB para placas rígidas.

Informes y vistas:

- [Validación principal](controller/validation/README.md),
  [DRC principal](controller/validation/drc-staging.json),
  [esquema principal renderizado por KiCad](controller/validation/controller-core-reva.svg).
- [Validación frontal](front-panel/validation/README.md),
  [DRC frontal](front-panel/validation/drc-staging.json),
  [esquema frontal renderizado por KiCad](front-panel/validation/front-panel-reva.svg).

## Cómo continuar

Abrir los `.kicad_pro` con KiCad 10. El esquema actual sigue generado por Python;
antes de editarlo manualmente, dejar de regenerarlo o trasladar los cambios al
generador. La PCB ya es editable: `tools/create_pcb_staging.py` se niega a sobrescribir
un archivo existente. `tools/sync_controller_pcb.py` actualiza las redes y huellas
de la principal sin tocar el contorno ni los taladros. `tools/sync_front_panel_pcb.py`
hace lo mismo para nuevas huellas del frontal; `tools/apply_front_panel_mechanics.py`
aplica su contorno sin necesitar KiCad y `tools/layout_front_panel_pcb.py` coloca y
rutea el frontal con Freerouting (el script es la fuente del layout). También se puede usar
«Actualizar PCB desde esquema» en KiCad conservando las posiciones revisadas.
`tools/layout_controller_pcb.py` es la fuente reproducible de la colocación de la
principal; el sincronizador ya no mueve huellas existentes. Tras el ruteo,
`tools/silkscreen_controller_pcb.py` dibuja la serigrafía (logo, título y
nombre de cada conector) y `tools/export_controller_print.py` saca la copia
1:1 en PDF para comprobar en papel. El logo se vectoriza una vez con
`tools/trace_silkscreen_logo.py`, que necesita Pillow, NumPy, scikit-image y
Shapely fuera del Python de KiCad.

Desde la raíz del repositorio (en Windows, con `PYTHONUTF8=1`: los scripts
leen JSON y CSV con texto en español):

```sh
python3 tools/generate_controller_core.py
python3 tools/check_front_panel.py
python3 tools/check_controller_core.py
python3 tools/validate_kicad.py
python3 tools/apply_front_panel_mechanics.py
<python de KiCad> tools/sync_controller_pcb.py
<python de KiCad> tools/layout_controller_pcb.py
<python de KiCad> tools/configure_controller_stackup.py
python3 tools/configure_controller_rules.py
<python de KiCad> tools/route_controller_pcb.py
<python de KiCad> tools/silkscreen_controller_pcb.py
<python de KiCad> tools/make_controller_3d_models.py
<python de KiCad> tools/export_controller_print.py
python3 tools/render_main_connector_map.py
<python de KiCad> tools/sync_front_panel_pcb.py
<python de KiCad> tools/layout_front_panel_pcb.py
kicad-cli pcb drc --schematic-parity --severity-all --format json -o hardware/controller/validation/drc-staging.json hardware/controller/kicad/controller-core-reva.kicad_pcb
kicad-cli pcb drc --schematic-parity --format json -o hardware/controller/validation/pcb/drc.json hardware/controller/kicad/controller-core-reva.kicad_pcb
kicad-cli pcb drc --schematic-parity --severity-all --format json -o hardware/front-panel/validation/drc-staging.json hardware/front-panel/kicad/front-panel-reva.kicad_pcb
python3 tools/export_front_panel_fab.py
python3 tools/export_controller_fab.py
```

Si el ejecutable no está en PATH, `validate_kicad.py` y `export_controller_print.py`
admiten `KICAD_CLI` y detectan la instalación habitual de macOS y de Windows. La
vista `controller/preview/pcb-staging-top.png` se renderiza con
`kicad-cli pcb render --side top`. Los detalles del enlace del frontal salen
con `--width 1600 --height 900 --quality high` y: `--zoom 5 --pan "5.4,-5.8,0"`
para `controller/preview/j104-wr-mm-top.png` (más `--rotate "-35,0,0"
--perspective` para `j104-wr-mm-3d.png`) y `--zoom 4 --pan "-6.2,2.2,0"` para
`front-panel/preview/j1-wr-mm-top.png`. Las piezas sin modelo 3D en KiCad 10.0 llevan
[cuerpos de sustitución](controller/kicad/OpenSaeco.3dshapes/README.md) que
genera `make_controller_3d_models.py`: valen para los renders y para ver
holguras a ojo, no para CAD mecánico, encaje en la carcasa ni distancias de
aislamiento. Los scripts de PCB requieren el Python incluido en KiCad y sus
bibliotecas.

Siguiente trabajo eléctrico: comprobar la principal impresa 1:1 contra la placa
original y los mazos, medir la
emisión conducida, revisar J101 frente a la salida de U303, y ensayar USB, watchdog,
motor del grupo, válvula y etapas de red según el
[plan de caracterización](../docs/HD8911/characterization-plan.md). Siguiente
trabajo mecánico: cerrar las comprobaciones previas al pedido del frontal
([layout.md](front-panel/layout.md#pendiente-antes-de-pedir)) y el adaptador de pantalla.

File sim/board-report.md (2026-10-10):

# Informe del modelo de placa

Generado por `tools/build_board_model.py` a partir de los netlists de las dos placas y del
[contrato de firmware](../firmware/common/signals.json). No sustituye a ERC/DRC.
Qué comprueba cada regla: [README del simulador](README.md).

**0 errores, 0 avisos.**

## Hallazgos

- **Nota** `pin-note`: stm32.BREW_DIR en PC14: Dominio de respaldo (pin RTC/LSE): salida de 2 MHz y 3 mA como máximo, una sola a la vez con PC13/PC15.
- **Nota** `pin-note`: stm32.BREW_FAULT_N en PB6: UCPD1_CC1: el BSP debe llamar a HAL_PWREx_DisableUCPDDeadBattery() antes de fiarse del nivel leído.
- **Nota** `pin-note`: stm32.WDT_KICK en PB4: Tras el reset es NJTRST con pull-up interno y además UCPD1_CC2: el BSP debe liberar JTAG y llamar a HAL_PWREx_DisableUCPDDeadBattery() antes de usarlo.
- **Nota** `power-domain`: esp32.KEY_INT_N (R3), esp32.KEY_SCL (R1), esp32.KEY_SDA (R2), esp32.LCD_CS_N (R4), esp32.LCD_RST_N (R5) tienen pull-up a controller:3V3_UI, no a controller:3V3_CORE: con controller:3V3_UI apagado los GPIO en alto lo alimentan a través de esas líneas.

## Señales

| MCU | Señal | Red | Pad | Pin real | Periférico | Reset | Camino |
|---|---|---|---|---|---|---|---|
| esp32 | KEY_INT_N | `KEY_INT_N` | 6 | GPIO6 | gpio_in |  |  |
| esp32 | KEY_SCL | `KEY_SCL` | 5 | GPIO5 | i2c_scl |  |  |
| esp32 | KEY_SDA | `KEY_SDA` | 4 | GPIO4 | i2c_sda |  |  |
| esp32 | LCD_BL | `BL_RAW` | 7 | GPIO7 | ledc | low | R218 |
| esp32 | LCD_CS_N | `CS_RAW` | 18 | GPIO10 | spi_cs | high | R215 |
| esp32 | LCD_DC | `DC_RAW` | 17 | GPIO9 | gpio_out |  | R216 |
| esp32 | LCD_MOSI | `MOSI_RAW` | 19 | GPIO11 | spi_mosi |  | R214 |
| esp32 | LCD_RST_N | `RST_RAW` | 12 | GPIO8 | gpio_out | high | R217 |
| esp32 | LCD_SCLK | `SCLK_RAW` | 20 | GPIO12 | spi_sclk |  | R213 |
| esp32 | UART_RX | `STM_TO_ESP` | 38 | GPIO2 | uart_rx |  | R211 |
| esp32 | UART_TX | `ESP_TX_RAW` | 35 | GPIO42 | uart_tx |  | R212 |
| esp32 | USB_DM | `USB_DM_RAW` | 13 | GPIO19 | usb_dm |  | R221 → U203 |
| esp32 | USB_DP | `USB_DP_RAW` | 14 | GPIO20 | usb_dp |  | R222 → U203 |
| esp32 | VBUS_SENSE | `USB_VBUS_SENSE` | 8 | GPIO15 | gpio_in |  | R225 |
| stm32 | BREW_CURRENT | `BREW_CURRENT_ADC` | 8 | PC0 | ADC1_IN6 |  |  |
| stm32 | BREW_DIR | `BREW_DIR_RAW` | 3 | PC14 |  | low | R503 → U501 |
| stm32 | BREW_FAULT_N | `BREW_FAULT_N` | 59 | PB6 |  |  |  |
| stm32 | BREW_PWM | `BREW_PWM_RAW` | 5 | PF0 | TIM1_CH3N AF6 | low | R501 → U501 |
| stm32 | BREW_SLEEP_N | `BREW_SLEEP_RAW` | 58 | PB5 |  | low | U602 → R505 → U501 |
| stm32 | BU_PRESENT_N | `BU_PRESENT_N` | 10 | PC2 |  |  | R408 |
| stm32 | BU_WORK_N | `BU_WORK_N` | 12 | PA0 |  |  | R410 |
| stm32 | DOOR_CLOSED_N | `DOOR_CLOSED_N` | 13 | PA1 |  |  | R406 |
| stm32 | FLOW | `FLOW_TIM` | 14 | PA2 | TIM2_CH3 AF1 |  | R404 |
| stm32 | GRINDER_CURRENT | `GRINDER_CURRENT_ADC` | 20 | PA6 | ADC2_IN3 |  | R412 |
| stm32 | GRINDER_EN | `GRINDER_EN_RAW` | 22 | PC4 |  | low | U604 → R718 → Q707 → U703 → Q708 → F703 → BR701 → U704 |
| stm32 | HEATER_EN | `HEATER_EN_RAW` | 23 | PC5 |  | low | U603 → R707 → Q705 → U701 → Q703 |
| stm32 | HEATSINK_AIR | `HS_NTC_ADC` | 36 | PB14 | ADC1_IN5 |  | R726 |
| stm32 | MAINS_ARM | `MAINS_ARM_RAW` | 60 | PB7 |  | low | U603 → R801 → Q701 → K701 |
| stm32 | NTC | `NTC_ADC` | 17 | PA3 | ADC1_IN4 |  | R402 |
| stm32 | PUMP_EN | `PUMP_EN_RAW` | 33 | PB11 |  | low | U604 → R714 → Q706 → U702 → Q704 |
| stm32 | RAIL_12V | `RAIL_12V_ADC` | 6 | PF1 | ADC2_IN10 |  | R702 → R701 |
| stm32 | RAIL_24V | `RAIL_24V_ADC` | 9 | PC1 | ADC1_IN7 |  | R705 → R704 |
| stm32 | UART_RX | `ESP_TO_STM` | 44 | PA10 | USART1_RX AF7 |  | R212 |
| stm32 | UART_TX | `STM_TX_RAW` | 43 | PA9 | USART1_TX AF7 |  | R211 |
| stm32 | UI_PWR_EN | `UI_PWR_EN` | 34 | PB12 |  | high | U302 |
| stm32 | VALVE_EN | `VALVE_EN_RAW` | 21 | PA7 |  | low | U602 → R511 → U502 → R513 → Q501 |
| stm32 | WATER_LEVEL | `WATER_LEVEL` | 11 | PC3 | ADC1_IN9 |  | R411 |
| stm32 | WDT_KICK | `WATCHDOG_KICK_RAW` | 57 | PB4 |  | low | R601 → U606 |

## Entradas analógicas

| Señal | Resultado |
|---|---|
| BREW_CURRENT | VREF 2.425 V; regulación a 1.01 A; 2.400 V/A; 0.34 mA/LSB |
| HEATSINK_AIR | 0 °C → 2.437 V, 120 °C → 0.200 V; 40 °C: 1.213 V, 0.030 °C/LSB; 80 °C: 0.482 V, 0.072 °C/LSB |
| NTC | 0 °C → 3.212 V, 150 °C → 0.537 V; 90 °C: 1.600 V, 0.032 °C/LSB; 125 °C: 0.863 V, 0.050 °C/LSB |
| GRINDER_CURRENT | 100 mV/A sobre 1.65 V; 0 A → 1.650 V, 4.8 A → 2.130 V; 8.1 mA/LSB |
| RAIL_12V | 15 V → 0.714 V; fondo de escala 69.3 V; 16.9 mV/LSB |
| RAIL_24V | 28 V → 1.333 V; fondo de escala 69.3 V; 16.9 mV/LSB |

## Excitación en el peor caso

Cada orden activa con los rails al mínimo (sim/osc_sim/drive.py): lo que cambia de estado y su margen frente al punto que garantiza el fabricante (sim/reference/devices.json).

| Señal | Carga | Cadena |
|---|---|---|
| BREW_DIR | J108.8 | U501 fwd: nSLEEP 3.17 V, EN/IN1 3.17 V, PH/IN2 3.17 V (VIH 1.5 V) |
| BREW_PWM | J108.7 | U501 rev: nSLEEP 3.17 V, EN/IN1 3.17 V, PH/IN2 0.00 V (VIH 1.5 V) |
| BREW_SLEEP_N | J108.7 | U501 rev: nSLEEP 3.17 V, EN/IN1 3.17 V, PH/IN2 0.00 V (VIH 1.5 V) |
| GRINDER_EN | J115.1 | Q707 VGS 3.20 V ≥ 2.75 V; Q708 disparado; U703 IF 9.5 mA ≥ 5 mA |
| HEATER_EN | J116.1 | Q703 disparado; Q705 VGS 3.20 V ≥ 2.75 V; U701 IF 9.5 mA ≥ 5 mA |
| MAINS_ARM | Q703.A2 | K701 bobina 21.5 V ≥ 16.8 V; Q701 VGS 3.20 V ≥ 2.75 V |
| PUMP_EN | J117.1 | Q704 disparado; Q706 VGS 3.20 V ≥ 2.75 V; U702 IF 9.5 mA ≥ 5 mA |
| UI_PWR_EN | J104.1 | U302 ON 3.20 V ≥ 1.1 V |
| VALVE_EN | J113.4 | Q501 VGS 11.00 V ≥ 4.5 V; U502 IN+ 3.17 V ≥ 2.4 V |

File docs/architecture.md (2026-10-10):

# Arquitectura Rev A

## Responsabilidades
- STM32: adquisición, límites, interlocks, estados y autoridad única sobre actuadores.
- ESP32: USB/web, configuración, telemetría y frontal; sin acceso directo a GPIO de potencia.
  El [USB-C de servicio](service-usb.md) está ya en el esquema y será la pasarela de banco.
- STM32G431RBT6 y ESP32-S3-WROOM-1U-N8R8 (antena externa U.FL) están en el
  [esquema de la principal](../hardware/controller/core-design.md), con sus pines
  asignados y ruteados; no hay BSP. Pines del ESP32 hacia el frontal en la
  [interfaz del frontal](../hardware/controller/front-panel-interface.md).
- Frontal nuevo: reproduce posiciones de botones y fijaciones de la PCB original,
  con display SPI mediante adaptador reemplazable. No depende del protocolo de JP21.
  [PCB ruteada](../hardware/front-panel/README.md) sobre la geometría recuperada;
  display de referencia ST7789 2,0" ([ADR-0001](adr/0001-front-panel-display-st7789.md)),
  MPN del panel pendiente.
- UART entre procesadores está dibujada a 3,3 V en el mismo dominio lógico;
  velocidad, framing, temporización y ensayos siguen pendientes.
- La principal recibe 230 V en JP17 e integra fusibles, varistor, la fuente
  aislada IRM-30-24, el relé general y todas las etapas de potencia, igual que la
  placa original; el filtro EMI de la Rev A es un X2 en la entrada, y el choque
  de modo común espera a medir la emisión conducida. J101 (12 V) y J112 (24 V) son
  entradas auxiliares de banco; J121 separa la fuente interna de J112.
- Las referencias confirman dos cargas a 24 V DC (grupo y válvula), dos a 230 V AC
  (calentador y bomba) y el molino a 320 V DC según el modo de servicio. El grupo
  tiene un DRV8876 y la válvula un low-side protegido, los dos desde el rail de
  24 V de la fuente integrada (o de J112 en banco). Calentador, bomba y molino
  usan triacs con optotriacs de cruce por cero tras el relé general K701. La
  [arquitectura de potencia](../hardware/power/power-architecture.md) define los
  dominios que conviven en la misma PCB sin cruzar la barrera de aislamiento.

```mermaid
flowchart LR
    U[USB / navegador] --> E[ESP32: interfaz]
    F[PCB frontal: botones I2C + display SPI] <--> E
    E -->|solicitudes| S[STM32: control e interlocks]
    I[Sensores acondicionados] --> S
    W[TPS3828 watchdog + puertas AND] --> S
    W --> G[DRV8876 grupo / 24 V]
    W --> V[Low-side válvula / 24 V]
    W --> K[Relé general K701]
    S --> W
    W -->|órdenes aisladas| P[Calentador / bomba / molino]
    K --> P
    G --> C[Cargas caracterizadas]
    V --> C
    P --> C[Cargas caracterizadas]
    H[Red, protecciones y fuente aislada integradas] --> P
    H --> G
    H --> V
```

## Núcleo actual
BOOT pasa a SAFE_IDLE con entradas simuladas válidas. Un fallo de interlocks o enlace
enclava FAULT. Todas las salidas permanecen inactivas. START siempre se rechaza;
STOP no borra FAULT. SAFE_IDLE es un estado lógico, no una garantía eléctrica.
El núcleo de firmware no incluye temporizadores, parser, HAL, GPIO, servicio del
watchdog ni adquisición real. El watchdog hardware ya existe en el esquema.

## Estados previstos
SELF_TEST, HOMING, READY, HEATING, GRINDING, BREWING y CLEANING: pendientes de límites,
calibración y recuperación por fase. Reinicio, reconexión y actualización no deben
reanudar ciclos automáticamente. El rearme futuro requiere condiciones válidas y
acción explícita, sin eliminar la causa del fallo por software.

## Fronteras de seguridad
El BSP futuro inicializará salidas inactivas antes del runtime. El TPS3828 y las
puertas AND U602–U604 anulan con el MCU en reset las órdenes de grupo, válvula,
calentador, bomba, molinillo y relé general. Los termostatos de la caldera siguen
siendo el corte térmico independiente.
Un semiconductor puede fallar en corto: poner un GPIO a cero no garantiza aislamiento.
USB y depuración solo serán accesibles en el dominio SELV, con separación
verificada respecto de red y del bus rectificado del molino.

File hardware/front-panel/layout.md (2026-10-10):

# Layout del frontal Rev A.0

Estado (2026-09-18): **PCB colocada, ruteada y con DRC limpio**, con paquete JLCPCB
candidato en [fabrication/](fabrication/). Pendiente de revisión del propietario y
de las comprobaciones de la última sección: **no pedir todavía**.

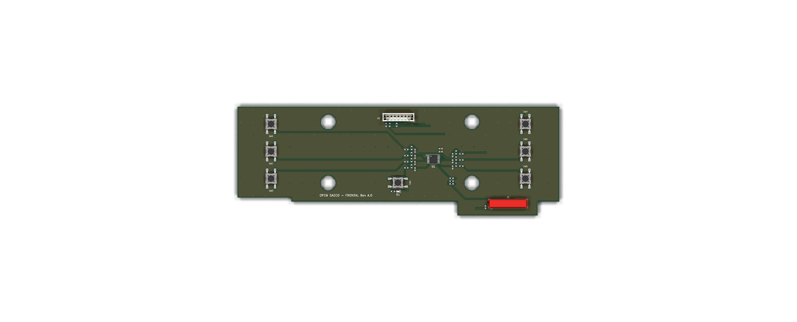
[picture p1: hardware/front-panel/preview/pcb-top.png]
Cara de componentes


La fuente es [tools/layout_front_panel_pcb.py](../../tools/layout_front_panel_pcb.py):
coloca, rutea con Freerouting y rellena masas. No editar la placa a mano sin portar
el cambio al script, igual que con el generador del esquema.

## Teclas, LED y registros del TCA9534

| TCA9534 | Pin | Red | Componente | Posición original | Centro (mm) |
|---|---:|---|---|---|---|
| P0 | 4 | KEY_1_N | SW1 | PB1 | (19,2; 9,9) |
| P1 | 5 | KEY_2_N | SW2 | PB2 | (19,2; 25,6) |
| P2 | 6 | KEY_3_N | SW3 | PB3 | (19,2; 41,2) |
| P3 | 7 | KEY_4_N | SW4 | PB8 (STBY) | (91,7; 43,5) |
| P4 | 9 | KEY_5_N | SW5 | PB4/PB6 | (164,6; 41,2) |
| P5 | 10 | KEY_6_N | SW6 | PB5 | (164,6; 25,6) |
| P6 | 11 | KEY_7_N | SW7 | PB7 | (164,6; 9,9) |
| P7 | 12 | LED_STBY_N | D1 + R7 | DL1 | (91,8; 48,5) |

El orden permite rutear los dos peines sin cruces; el firmware traduce bit → tecla.
Teclas activas a 0 con 10 kΩ a 3,3 V, 1 kΩ serie y 100 nF. El LED (rojo 0603,
KT-0603R) va de 3,3 V por R7 = 470 Ω al pin P7: se enciende con P7 a 0 (≈2,7 mA).
TI SCPS197D: P-port push-pull, ≥8 mA a VOL = 0,5 V y todos los puertos entradas al
arrancar, así que el LED está apagado hasta que el firmware lo configure.

Secuencia para el firmware (sustituye la configuración anterior de ocho entradas):

1. Output (`0x01`) = `0xFF`: P7 alto, LED apagado antes de convertirlo en salida.
2. Polarity (`0x02`) = `0x00`.
3. Configuration (`0x03`) = `0x7F`: P0–P6 entradas, P7 salida.
4. Leer Input (`0x00`) y usar solo los bits 0–6; el bit 7 refleja la salida.
5. LED: bit 7 de Output a 0 = encendido, a 1 = apagado.
6. Tras fallo de bus o reconexión, reescribir en el mismo orden (Output antes que Configuration).

## Colocación

- Pulsadores SW1–SW7 (HRO K2-1102SP-A4SC-04, 6 × 6 × 4,3 mm; el propietario midió
  4,3 mm en el original) centrados en las cotas de [mechanical.md](mechanical.md),
  con las patas arriba/abajo como el original (SW4 girado 90°). Los pads de tecla
  miran hacia U1 y los de masa hacia fuera, cada uno con su vía.
- J1 (Würth WR-MM 690367181672, el conector del JP3 original) con el cuerpo
  centrado en la zona del JP3 (x 143…166, y 51,5…59,3), cara de componentes, pin 1
  abajo a la izquierda y fila impar al sur. El propietario confirmó ≥16 mm libres delante de la pestaña.
- J2 (JST PH 8 vertical, entrada desde arriba) arriba al centro, donde estaban
  JP1/JP2; mismos pads que el lateral anterior. Orden del cable PH del módulo Waveshare 2": VCC GND DIN CLK CS DC RST BL.
- U1 en el centro (112; 30) con C1/C2 junto a VCC y dos peines RC: P0–P3 a la
  izquierda y P4–P6 a la derecha; R1–R3 (pull-ups I²C/INT) bajo el peine derecho;
  R4–R6 bajo J2; C3 junto al pin 1 de J1.
- Todas las piezas en la cara superior; J1 y J2 son THT.

## Ruteo

Freerouting 2.4.1 rutea desde un DSN exportado por KiCad sin la red GND_UI, que
va por dos rellenos de masa (F.Cu y B.Cu) con vías de cosido cada 7 mm, más una vía
junto a cada pad de masa. Zonas de exclusión de 0,6 mm alrededor de los taladros
Ø8,4. Resultado: 297 segmentos y 192 vías (141 de cosido). F.Cu lleva sobre todo
las líneas de tecla por pasillos rectos; B.Cu lleva el bus SPI y los 3,3 V de J1 a J2
y el I²C de J1 a U1, con el plano de masa inferior entero en la mitad izquierda.

Reglas del proyecto, dentro de la capacidad estándar de JLCPCB para dos capas:
pista y separación de 0,2 mm (Freerouting estrecha a 0,15 mm la entrada a los pines
del TSSOP; mínimo del proyecto 0,15 mm), 3V3_UI en clase Power de 0,4 mm, vías de
0,6/0,3 mm y 0,5 mm de cobre a borde. Los pads GND de J1/J2 van unidos al relleno
sin alivio térmico y los de U1 solo por su pista a la vía.

## Verificación

- ERC nativo: 0 errores y 0 avisos; netlist de KiCad = diseño (42 componentes, 118 pines).
- DRC KiCad 10.0.6 con paridad y todas las severidades: **0 infracciones, 0 conexiones
  pendientes y 0 diferencias con el esquema** ([informe](validation/drc-staging.json)).
- Freerouting informa 32 «violations» internas sin detalle en su registro; la
  referencia es el DRC de KiCad con las reglas del proyecto, que no encuentra ninguna.
- Vistas: [cara superior](preview/pcb-top.png), [cara inferior](preview/pcb-bottom.png)
  y [detalle de J1](preview/j1-wr-mm-top.png).
  El modelo 3D de los pulsadores es el C&K PTS645 de la biblioteca de KiCad
  (mismo cuerpo 6 × 6 × 4,3 mm), solo como representación.

## Paquete JLCPCB

| Archivo | Contenido |
|---|---|
| [front-panel-reva-gerbers.zip](fabrication/front-panel-reva-gerbers.zip) | Gerber de 2 capas (extensiones Protel, máscara restada de la serigrafía), Excellon en mm con PTH y NPTH separados, y mapas de taladros |
| [front-panel-reva-bom-jlcpcb.csv](fabrication/front-panel-reva-bom-jlcpcb.csv) | 12 líneas / 41 posiciones: Comment, Designator, Footprint, LCSC Part # |
| [front-panel-reva-not-assembled.csv](fabrication/front-panel-reva-not-assembled.csv) | J1 (Würth WR-MM), sin stock en JLCPCB el 2026-10-08: se compra aparte y se suelda a mano |
| [front-panel-reva-cpl-jlcpcb.csv](fabrication/front-panel-reva-cpl-jlcpcb.csv) | Designator, Mid X, Mid Y, Layer, Rotation (todas Top) |

Opciones previstas: 2 capas, 1,6 mm (espesor del original sin medir), máscara
verde, acabado a elección. Los taladros Ø8,4 son contorno fresado, no taladros.
Montaje: cara superior; J1 y J2 THT (JLCPCB los monta por soldadura por ola o a mano).

En la vista previa de montaje de JLCPCB comprobar, antes de confirmar:

- U1: pin 1 (arriba a la izquierda de la huella) contra el punto del encapsulado.
- D1: cátodo en el pad 1, el de la derecha, según la marca del LED.
- SW1–SW7: patas arriba/abajo; SW4 girado 90°.
- J1: pin 1 en el extremo izquierdo, junto al taladro sin metalizar de 1,5 mm en
  el que entra el pestillo del cable; la marca de pin 1 de la serigrafía queda debajo.
- J2: boca del PH hacia el borde superior de la placa.

El CPL incorpora la [auditoría por componente](../assembly/placement-audit.md):
U1 +270°, D1 +180° y J2 +180° con el centro trasladado 7 mm desde el pin 1
en los ejes locales de la huella. SW1–SW7 conservan su giro; la comparación
relaciona sus cuatro patas físicas con los dos contactos eléctricos.
Las 41 posiciones montadas tienen correspondencia geométrica. Esto no sustituye
la revisión de la previsualización del pedido ni las verificaciones mecánicas.

## Pendiente antes de pedir

- De [mechanical.md](mechanical.md): calibre del alto del cuerpo (54,3), la pestaña
  (62,3) y la separación entre taladros (82,1 × 35,0), y superposición 1:1.
- Función de SP1–SP3 (hoy bajo el relleno de masa, sin pad propio).
- Espesor de la PCB original y holgura real de la carcasa delante de J1 (WR-MM, 6,1 mm de alto) y J2 (4,8 mm).
- Adaptador de pantalla definitivo; J2 está preparado para el cable del módulo Waveshare.
- Stock y precio en el momento del pedido; las cifras del catálogo son del 2026-09-18.

## Regenerar

```sh
python3 tools/generate_front_panel.py
python3 tools/check_front_panel.py
python3 tools/validate_kicad.py
<python de KiCad> tools/sync_front_panel_pcb.py
<python de KiCad> tools/layout_front_panel_pcb.py            # rutea de nuevo
<python de KiCad> tools/layout_front_panel_pcb.py --silk-only # solo textos y modelos
kicad-cli pcb drc --schematic-parity --severity-all --format json -o hardware/front-panel/validation/drc-staging.json hardware/front-panel/kicad/front-panel-reva.kicad_pcb
python3 tools/export_front_panel_fab.py
```

Freerouting no es determinista: cada ruteo nuevo exige repetir DRC y revisión visual.
Si cambia la PCB, repetir también la auditoría de colocación descrita en
[assembly](../assembly/README.md) antes de exportar.
`FREEROUTING` permite indicar el ejecutable si no está en la ruta por defecto de Windows.

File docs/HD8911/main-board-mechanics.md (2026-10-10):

# Mecánica de la PCB principal 421941308981/01

Medición fotogramétrica realizada el 2026-09-17 a partir de IMG_1098–IMG_1101.
El propietario aceptó estas dimensiones el 2026-09-17 como línea base mecánica
de la Rev A para continuar el layout con tolerancias normales de fabricación.
Las fotos originales son 5712 × 4284 px. IMG_1098 e IMG_1099 muestran las dos
dimensiones exteriores sujetas con un calibre de nonio de 0,05 mm; IMG_1098
ofrece además una vista casi normal sobre una cuadrícula de 10 mm. IMG_1100 e
IMG_1101 se utilizaron para comprobar orientación, canto y conectores.

El origen mecánico adoptado es la esquina superior izquierda de IMG_1098, con
la cara de componentes hacia el observador. X crece hacia la derecha e Y hacia
abajo. La orientación se identifica por JP21 rojo arriba a la izquierda y los
conectores de potencia en el borde inferior.

## Cotas recuperadas

| Elemento | X (mm) | Y (mm) | Diámetro (mm) | Incertidumbre | Fuente |
|---|---:|---:|---:|---:|---|
| Contorno | 0…141,6 | 0…135,2 | — | ±0,15 mm | Lectura directa del calibre |
| MH1 | 23,5 | 46,3 | 3,5 | centro ±0,6; diámetro ±0,3 mm | IMG_1098 rectificada |
| MH2 | 37,8 | 112,8 | 3,5 | centro ±0,6; diámetro ±0,3 mm | IMG_1098 rectificada |
| MH3 | 136,5 | 128,8 | 3,5 | centro ±0,6; diámetro ±0,3 mm | IMG_1098 rectificada |

El contorno observado es rectangular y no se distinguen fresados interiores.
Las esquinas parecen rectas; la resolución y los elementos que tapan el borde
no permiten asignar un radio de esquina. La Rev A usa un
rectángulo de 141,6 × 135,2 mm y taladros NPTH de 3,5 mm.

Comprobaciones geométricas útiles:

| Distancia | Valor derivado (mm) |
|---|---:|
| MH1–MH2 | 68,0 |
| MH2–MH3 | 100,7 |
| MH1–MH3 | 139,9 |
| MH3 al borde derecho | 5,1 |
| MH3 al borde inferior | 6,4 |

## Cómo se obtuvo

La lectura del primer calibre coloca el cero del nonio entre 141 y 142 mm y la
coincidencia corresponde aproximadamente a 141,6 mm. En la segunda foto el cero
queda entre 135 y 136 mm, aproximadamente 135,2 mm. No se usa la cuadrícula para
esas dos cotas: sirve como control independiente y para ubicar centros.

Se tomó el cuadrilátero formado por los cuatro bordes y se proyectaron los centros
de los tres taladros a un rectángulo de 141,6 × 135,2 mm. El diámetro se estimó
con la escala local alrededor de cada centro. La dispersión visual entre ejes X/Y
y el desenfoque del canto determinan las incertidumbres indicadas.

## Lo que estas fotos no cierran

- Espesor del laminado: la vista lateral no permitía medirlo. El propietario lo
  midió el 2026-09-19 en la placa original: 1,6 mm.
- Altura máxima de componentes: el disipador original mide 40 mm de ancho y 35 mm
  de alto sobre la placa, así que hasta 35 mm cabe con seguridad (propietario,
  2026-09-19). No se conoce todavía el margen por encima de esa cota.
- Huellas de conectores: se cuentan cavidades y se distinguen familias mecánicas,
  pero el paso y las dimensiones de retención no alcanzan tolerancia de huella.
- Posición exacta de cada conector: una estimación fotográfica sirve para preparar
  la colocación, pero no para garantizar que encaje el arnés rígido.
- Radio de esquina, tolerancia de fresado y holgura necesaria en la carcasa.

## Posición de conectores recuperada

La sustitución directa exige conservar la llegada de los mazos, por lo que se
adopta una segunda calibración sobre IMG_1098. Se ajustó el borde de la imagen al
rectángulo aceptado y se contrastó en IMG_1101 qué conectores entran por el
lateral izquierdo. Las coordenadas siguientes son orígenes de huella KiCad, no
centros de carcasa:

| Conector original | Referencia Rev A | X (mm) | Y (mm) | Giro | Entrada |
|---|---|---:|---:|---:|---|
| JP21 | J104 | 6,2 | 6,5 | 90° | borde superior |
| JP16 | J108 | 3,0 | 64,5 | 90° | lateral izquierdo |
| JP14 | J107 | 3,0 | 73,5 | 90° | lateral izquierdo |
| JP3 | J113 | 3,5 | 125,3 | 0° | borde inferior |
| JP22 | J109 | 19,0 | 128,2 | 0° | borde inferior |
| JP13 | J105 | 29,0 | 125,3 | 0° | borde inferior |
| JP5 | J106 | 38,2 | 125,3 | 0° | borde inferior |

La incertidumbre asignada es ±1,5 mm, suficiente para congelar el placement de
Rev A y preparar una verificación física 1:1. J106 va 0,3 mm al oeste de la foto
desde el 2026-09-29, para que la cabecera A2506 no toque U702. Desde el
2026-09-22 todos los conectores de mazo de la Rev A son de entrada vertical. El mapa reproducible está en
`hardware/controller/validation/main-connector-map.svg` y las coordenadas
estructuradas en `hardware/controller/mechanical-source.json`.

JP8, JP19, JP24, JP17, JP1 y JP9 también conservan su posición original y están
en el esquema y en la PCB; sus coordenadas están en `mechanical-source.json` y en
el [layout](../../hardware/controller/layout.md).

La geometría quedó liberada para el layout Rev A, que ya está colocado y ruteado.
Esta aceptación cierra contorno y fijaciones; no libera la PCB, pendiente de la
comprobación 1:1 con la placa original y los mazos.

## Familias mecánicas que ya pueden acotarse

- JP21 coincide visual y dimensionalmente con un TE Micro-MaTch Industrial rojo,
  hembra en placa, entrada lateral, dos filas. La variante de 20 posiciones
  [TE 2-338070-0](https://www.te.com/en/product-2-338070-0.html) es el candidato
  más cercano: 2,54 mm entre contactos de una misma fila, filas escalonadas y
  retención por patas deformadas. El recuento y el patrón de soldadura deben
  confirmarse en la cara inferior antes de asignar su huella.
- Los conectores blancos pequeños presentan paso fotográfico cercano a 2,5 mm y
  geometría similar a JST XH de entrada lateral. La
  [especificación XH](https://www.jst-mfg.com/product/pdf/eng/eXH.pdf) confirma
  2,5 mm y PCB nominal de 1,6 mm, pero el color y la silueta no prueban fabricante.
- Las lengüetas de potencia son compatibles en tamaño aparente con FASTON 250:
  6,35 × 0,8 mm. Por ejemplo, TE documenta esas dimensiones para
  [63066-1](https://www.te.com/pt/product-63066-1.html), pero no se ha medido el
  patrón de anclaje de la pieza original y esa referencia no queda seleccionada.

> **Actualizado:** la revisión con nonio del 2026-09-24 descartó JST XH para
> los conectores blancos. El propietario identificó JP3, JP5 y JP13 como HR
> A2506WV, JP8 y JP24 como LEOCO 3941 y 5001, JP17 y JP19 como TE RAST 5 y JP1/JP9
> como lengüetas TE 63824-1 (ver [photos.md](photos.md) y el
> [layout](../../hardware/controller/layout.md)). El 2026-10-01 identificó el
> conector del enlace con el frontal como Würth WR-MM 690367181672, de 16
> contactos, en las dos placas, unidas por un cable plano 1:1 de 16 hilos; el
> recuento fotográfico de 20 para JP21 era un error. JP14, JP16 y JP22 los
> identificó el 2026-10-10: HR A2506WV-02P, HR A2506WV-08P y JST ZH B3B-ZR.

Estas identificaciones reducen la búsqueda de repuestos, pero continúan como
candidatos. La huella se cerrará con una foto ortogonal de soldaduras o una medida
directa entre pines; la disponibilidad JLCPCB se evaluará después de fijar la serie.

Los conectores nuevos J101–J104 no intentan copiar estas piezas de la Saeco.
La Rev A usa JST XH vertical para la entrada aislada de 12 V, cabezales 1×6 para
servicio y, para el frontal, el mismo Würth WR-MM 690367181672 del enlace
original. JP21 conserva valor como referencia de posición y para documentar la
placa original, no como contrato eléctrico: el pinout del enlace es nuevo.

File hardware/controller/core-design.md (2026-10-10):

# Principal Rev A — esquema

El esquema tiene 187 posiciones eléctricas en una sola hoja:
[esquema KiCad](kicad/controller-core-reva.kicad_sch),
[vista SVG auxiliar](preview/core.svg) y [BOM](bom-draft.csv). Cubre toda la
placa de sustitución, lógica, 24 V y red, pero nada está ensayado. La
[PCB](layout.md) está colocada y ruteada con DRC limpio; ver
[proyecto y validación](../kicad-workflow.md).

## Alcance del esquema

- U101: STM32G431RBT6, LQFP64; alimentación, desacoplo, NRST, BOOT0 y SWD.
- U201: ESP32-S3-WROOM-1U-N8R8 (LCSC C2980300); alimentación, EN con RC, BOOT y
  UART de programación. Usa antena externa de 2,4 GHz por U.FL: su antena impresa
  y la zona de exclusión del WROOM-1 ocupaban el 10 % de la placa, y ese espacio
  hace falta para la zona de red. La antena y su cable (U.FL/IPEX MHF1) son un
  accesorio del arnés, fuera de la BOM de la PCB. Hay que fijarla lejos de la
  caldera y de chapa, y comprobar la cobertura con la carcasa cerrada.
- UART entre MCU: STM PA9/TX → ESP GPIO2/RX; ESP GPIO42/TX → STM PA10/RX. Van
  por el lado este del módulo, junto a R211/R212 (antes GPIO18/17).
- Conexión J104 al frontal, con el mismo pinout eléctrico que J1 del frontal.
- Resistencias serie candidatas de 33 Ω en las dos salidas UART y seis señales
  del display. Las de la UART van junto a sus emisores; las seis del display,
  en fila bajo J104, a la entrada del cable del frontal.
- Entrada de 12 V DC aislada de banco (J101), protección de entrada, buck de
  3,3 V y corte controlado del rail del frontal.
- Divisor y filtro del NTC JP13 hacia PA3/ADC1_IN4, con diagnóstico de abierto/corto.
- Alimentación a 12 V y entrada open collector del caudalímetro JP5 hacia
  PA2/TIM2_CH3; pinout físico 1=señal, 2=GND y 3=VCC. Desde el 2026-10-07
  (issue #8) la alimentación sale por R413 (390 Ω, anti-surge de 0,66 W) con
  C408 junto al conector. El Digmesa gasta menos de 8 mA y funciona desde
  3,8 V, así que le quedan unos 7,9 V con 11 V en el raíl. Un corto en el mazo
  se queda en 32 mA y 0,4 W, sin hundir `12V_PROTECTED` ni abrir F301.
- Sensor de agua JP22 alimentado a 3,3 V y señal filtrada hacia PC3/ADC12_IN9;
  orden rojo=VCC, blanco=señal y negro=GND. Desde el 2026-10-07 lo alimenta
  U304, otro TPS2553, con R306 = 210 kΩ: 110–150 mA, de sobra para un sensor
  de nivel y lejos del límite de U301. Con JP22 desconectado PC3 queda al aire
  (issue #7): R415 (pull-up a `WATER_VCC`) y R416 (pull-down a GND), de
  100 kΩ, tienen huella y no se montan hasta que WL-01 diga si la salida es
  de colector abierto o push-pull.
- Entradas activas a cero para JP14 (PA1) y los micros de presencia (PC2) y
  trabajo (PA0) de JP16, con pull-up, resistencia serie y filtro RC.
- J105–J108 son HR A2506WV (-02P, -03P, -02P y -08P) y J109 una JST ZH B3B-ZR
  de 1,5 mm, todas identificadas por el propietario (JP14, JP16 y JP22 el
  2026-10-10). Cada A2506 se orienta con la pared cercana a los pines del lado
  que tiene en la original (ver [layout](layout.md#jp14-jp16-y-jp22)); V1..V8 de
  JP16 caen en los pads 8..1 de J108, con V1 junto a JP21. Las vías V1/V2 de JP16 llegan a un DRV8876 para el motor del grupo.
- J110 añade USB-C 2.0 nativo al ESP32, protección ESD, detección de VBUS y
  resistencias CC. J111 permite alimentación limitada de banco y queda abierto.
- J112 recibe 24 V DC aislados para los actuadores y entra por su propio
  fusible F306 (2 A) y Schottky D308; F303/D304/C501 forman la rama protegida
  del motor del grupo y F304/D305 la rama separada de válvula.
- PS701 integra la alimentación de red como módulo IRM-30-24; U303 deriva 12 V,
  y K701 corta de forma general la fase entregada a las cargas peligrosas.
- U501 implementa inversión, PWM, `nSLEEP`, diagnóstico `nFAULT`, límite de
  corriente candidato a 1 A y lectura `IPROPI` hacia el ADC del STM32.
- PA7 gobierna la electroválvula mediante U502, Q501 y una entrada con pull-down.
  J113 reproduce JP3: el pin 1 de la original (pad 5 de J113) a +24 V, el 2
  (pad 4) al retorno conmutado y el resto sin uso.
  D306 proporciona rueda libre externa.
- U601 supervisa 3,3 V y PB4 como watchdog. Su salida open-drain comparte
  `STM_NRST`; U605 (Schmitt) lo cuadra como `STM_NRST_BUF` y U602 solo permite
  activar `nSLEEP` y la válvula mientras reset esté inactivo. R603/R604 mantienen ambas órdenes a cero durante el arranque.
- PF1/ADC2_IN10 y PC1/ADC2_IN7 miden las entradas de 12 V y 24 V mediante
  divisores 200 kΩ/10 kΩ y filtros de 100 nF. J114 expone 3,3 V, 12 V y 24 V
  para medida en banco, cada uno entre dos masas y tras 10 kΩ; no es una
  entrada de alimentación.

- Etapas de calentador (U701/Q703), bomba (U702/Q704) y molinillo
  (U703/Q708/F703/BR701): MOC3083 de cruce por cero y BTA24 tras K701, con el
  LED de cada opto gobernado por un BSS138LT1G desde 12 V. Órdenes PC5, PB11 y PC4
  a través de U603/U604. U704 (TMCS1133B4A) mide la corriente del molinillo en
  la línea + de JP8, cruzando la barrera, y la lleva a PA6 por R412/C407. Detalle
  en [power-architecture.md](../power/power-architecture.md).

JP8 y JP24 son J115 y J117, las LEOCO 3941P03*000 y 5001P020013 identificadas
por el propietario, con huella según el plano del fabricante. JP19 es J116 y JP17
es J118, los TE 1971845-4 y 1971845-3, también con huella según el plano. Los dos
FASTON de PE son J119/J120, TE 63824-1 casados con la foto del propietario.

Los GPIO sin uso llevan NC: no están conectados en el circuito y no equivalen a
ninguna vía del arnés Saeco.

## Alimentación y arranque

J101 usa un JST XH vertical de dos contactos (B2B-XH-A, `C158012`): `12V_BENCH_RAW` y `GND_UI`. Debe
recibir 12 V DC de una fuente AC/DC aislada y certificada; no admite conexión a
red. F305 (1 A) protege su rama y D307 (SS34) bloquea polaridad inversa y la une
a `12V_PROTECTED` en OR con la salida de U303, que llega por F301 y D301. D302
(SMAJ15A) limita transitorios antes del regulador: empieza a conducir entre 16,7 y
18,5 V, por debajo de los 20 V máximos del VDD de U502 y del caudalímetro de J106.
Hasta el 2026-10-05 era un SMAJ18A, que no conduce hasta 20–22,1 V.

En la máquina, PS701 (IRM-30-24) da `24V_INTERNAL_RAW`, que J121, puenteado de
fábrica, une a `24V_ACT_RAW`: de ahí salen el motor del grupo, la válvula, la
bobina de K701 y U303, que baja a 12 V sobre `12V_ISO_RAW`.
En banco, J112 inyecta 24 V limitados con J121 abierto, y J101 12 V para la
lógica sola. Hasta el 2026-10-05 J101 compartía nodo con la salida de U303: sin
24 V, el nodo SW del buck quedaba por encima de su VIN (máximo absoluto
VIN + 0,3 V) y su diodo interno devolvía tensión a `24V_ACT_RAW`. Ahora J101 y
U303 se unen en OR por D307 y D301, y con 24 V presentes manda la tensión más
alta sin que ninguna fuente alimente a la otra.
Ver la [arquitectura de alimentación](../power/power-architecture.md).

U301 es un AP63203WU-7 síncrono de salida fija a 3,3 V/2 A. El circuito implementa
la tabla 2 de su hoja de datos: L301=3,9 µH, C301=10 µF/25 V, C304+C305=2×22 µF/10 V
y C303=100 nF entre BST y SW. C302 y C306 añaden desacoplo de alta frecuencia.
Desde el 2026-10-07 (issue #3) el condensador de entrada que pide la hoja es
C315 (10 µF/50 V X7R 1206, el mismo que C310), justo detrás de C302 entre VIN y
GND. C301 queda como bulk del raíl junto a D301/D307, a unos 30 mm de pista del
conmutador. Según las curvas de polarización DC del Component Library de
Samsung (25 °C, 1 Vrms, 1 kHz, leídas el 2026-10-07), a 12 V C315 conserva
5,0 µF de 10,8 y C301 (25 V X5R 0805) 2,0 µF. Trabajar al 24 % de la tensión
nominal no evita perder la mitad, pero C315 da 2,5 veces más que C301. El
rizado real de VIN queda para PS-07.
`3V3_CORE` alimenta ambos procesadores.

U302 (TPS2553DBVR desde el 2026-10-07, issue #8) genera `3V3_UI` desde
`3V3_CORE`. PB12 del STM32 controla `UI_PWR_EN`; R301=100 kΩ lo mantiene activo
durante reset. R304=49,9 kΩ limita la corriente a 475–565 mA (TI SLVS841F, 7.5),
por debajo de 1,5 A de los contactos WR-MM y del límite de U301. Además, el
TPS2553 tiene apagado térmico. Un corto en el cable del frontal se queda en
U302 y no hunde `3V3_CORE`, así que los dos MCU siguen vivos aunque el reset no
aísle el frontal. El TPS22918 que había no tenía límite de corriente ni apagado
térmico. El TPS2553 no descarga su salida al apagarse: R305=1 kΩ lo hace, como
el QOD del TPS22918, y gasta 3,3 mA con el frontal encendido. Su arranque suave
interno sustituye a C307. FAULT queda sin conectar. Esta rama permite cortar el
frontal y reduce su corriente de arranque. La rampa, descarga y
posible backfeed deben medirse con el display definitivo. `GND_UI` es la masa
lógica común; el aislamiento lo da PS701 (o la fuente de banco de J101/J112).

El símbolo del STM32 sigue la tabla de pads LQFP64 de ST
(`STM32_open_pin_data`, la misma del símbolo oficial de KiCad): VSS/VDD en 15/16
y VSSA/VREF+/VDDA en 27–29. Hasta el 2026-10-01 dibujaba los pads 12–29 con el
orden de la serie F; lo detectó el [modelo de placa](../../sim/README.md).
VDDA y VREF+ del STM32 quedan conectados a 3V3_CORE y desacoplados localmente.
VREFBUF interno debe permanecer deshabilitado mientras VREF+ se alimenta así.
Para adquisición de precisión queda pendiente evaluar filtrado y referencia,
junto con la red de sensores. VBAT comparte 3V3_CORE; no hay batería.

Desacoplo inicial STM32: 100 nF por VDD, 4,7 µF común, 10 nF + 1 µF en VDDA y
100 nF + 1 µF en VREF+. EN del ESP usa 10 kΩ + 1 µF; se debe verificar su rampa
con la fuente real. Estas son elecciones para revisión, no un ensayo de arranque.
Fuentes: [ST DS12589, figuras 10 y 16](https://www.st.com/resource/en/datasheet/stm32g431rb.pdf)
y [guía de hardware ESP32-S3, alimentación y reset](https://docs.espressif.com/projects/esp-hardware-design-guidelines/en/latest/esp32s3/schematic-checklist.html).

El módulo requiere además cotejar el land pattern y el pad expuesto con su
[hoja de datos](https://documentation.espressif.com/esp32-s3-wroom-1_wroom-1u_datasheet_en.html).
El pad 41 está conectado a masa. Los pads 28/29/30, usados por la variante con
PSRAM octal, no se conectan a periféricos externos.

Para el primer BSP se propone HSI interno del STM32 y USART1 AF7 en PA9/PA10.
Faltan la configuración de reloj, tolerancia del enlace y opciones de arranque.
NRST debe conservar función reset: no reconfigurarlo como PG10 de uso general.
J102 y J103 usan cabezales 1×6 de 2,54 mm con numeración propia; el orden no
corresponde al conector Cortex de 10 pines ni a un adaptador USB-serie concreto.
Su pin de 3V3 es referencia para el programador; no se alimenta desde él.

J104 y J1 del frontal usan el Würth WR-MM 690367181672 que el propietario
identificó en el enlace original (16 contactos a 1,27 mm al tresbolillo). El
cable original es plano 1:1 de 16 conductores y su pestillo entra en un taladro de
1,5 mm junto al pin 1, que fija el sentido; el pinout es nuevo, no el de JP21 Saeco.
Las masas intercaladas junto a SCLK y MOSI forman parte del contrato del cable.

## USB de servicio y control en banco

J110 es un HRO TYPE-C-31-D-06 (`C2689964`) USB 2.0 de entrada vertical,
junto a la zona del conector rojo JP21 original. GPIO19 y
GPIO20 del ESP32-S3 implementan D− y D+ a través de R221/R222 de 33 Ω. U203
(USBLC6-2SC6, `C7519`) protege ambas líneas y R223/R224 de 5,1 kΩ anuncian un
dispositivo USB en CC1/CC2. GPIO15 recibe `USB_VBUS_SENSE` mediante 100 kΩ/100 kΩ
y 10 nF, necesario para que un equipo autoalimentado detecte la presencia del host.
La carcasa se une provisionalmente a `GND_UI`; la política EMI/chasis se revisará
con el layout y la envolvente final.

El par D+/D− está ruteado para 90 Ω diferencial (0,29/0,20 mm sobre el plano de
In1.Cu), con U203 junto a J110 y R221/R222 junto al ESP32; ver
[service-usb.md](../../docs/service-usb.md).

La vía de alimentación USB es deliberadamente opcional: F302 limita a 500 mA,
J111 es un puente de soldadura que se fabrica **abierto** y D303 impide retorno
hacia VBUS. Cerrado en banco, inyecta aproximadamente 5 V en la entrada del buck
existente; sirve para firmware y lógica con consumo controlado. No se autoriza
alimentar actuadores, el frontal completo ni la máquina desde el PC. Con J111
abierto, USB sigue disponible para datos cuando J101 alimenta la lógica. El uso
de servicio y el protocolo se detallan en [USB de banco](../../docs/service-usb.md).

## Lo que falta en la principal

| Bloque | Siguiente entrega | Dependencia |
|---|---|---|
| Fuente aislada | Confirmar IRM-30-24 con los consumos reales (PS-01 a PS-03) | Consumos simultáneos, temperatura interior |
| Protección de red | MOV RV701 (fusibles de red cerrados en la issue #1: 1500 A, F701 de 12 A y F702 de 2 A; filtro EMI de la Rev A: X2 C707 y C708 DNP en el molinillo) | Energía de sobretensión; emisión conducida del prototipo (EM-01) para C708 y el choque de la Rev B |
| Alimentación lógica | Ensayar AP63301/AP63203, térmica, ripple y transitorios; J101 en OR con U303 por D307/D301 | Presupuesto de corriente y prototipo cargado |
| Frontal | Ensayar corte/descarga de 3V3_UI y prevención de backfeed | Display definitivo y comportamiento al apagar UI |
| USB | Comprobar enumeración y consumo de banco | Acceso mecánico y dominio aislado verificado |
| Supervisión | Ensayar el [watchdog e interlock implementados](../power/watchdog-interlock.md) | Firmware PB4, osciloscopio y análisis de fallos |
| Sensores | Caracterizar salida del nivel capacitivo y ensayar adaptadores | Niveles lleno/vacío de JP22 y estados de contactos JP16 |
| Motor del grupo | Ensayar DRV8876, corriente, bloqueo, inversión, frenado, ruido y térmica | Fuente 24 V limitada, motor real y firmware de fallo |
| Electroválvula | Ensayar la [etapa low-side implementada](../power/valve-driver.md), corriente, liberación y transitorios | Fuente 24 V limitada, bobina real y osciloscopio |
| Etapas de red | Ensayar calentador, bomba y molinillo | [Plan de caracterización](../../docs/HD8911/characterization-plan.md) y revisión de aislamiento |
| Mecánica | Comprobación 1:1 y acoplamiento de las cabeceras con los mazos | Placa original, mazos y muestras |

### Puente H del motor del grupo

La resistencia medida del motor del grupo es 54,7 Ω. A 24 V equivale a
`24 V / 54,7 Ω = 0,439 A` como estimación resistiva con el rotor parado en la
posición de medida. No se usa como corriente nominal: las escobillas, la posición
del colector, la temperatura y la fuerza contraelectromotriz cambian el valor.

U501 es un
[**DRV8876PWPR**](https://www.ti.com/lit/ds/symlink/drv8876.pdf) (TI, `C575551`), puente H para 4,5–37 V,
3,5 A pico y encapsulado HTSSOP-16 con pad térmico. Integra lectura proporcional
`IPROPI`, regulación de corriente y `nFAULT`, lo que evita un shunt de potencia y
encaja con la autodosis basada en corriente del grupo. La hoja de datos incluye
precisamente un caso de 24 V, 0,5 A RMS y límite de 1 A.

La primera revisión implementa `RIPROPI = 2,4 kΩ`, `RREF1 = 18 kΩ` y
`RREF2 = 49,9 kΩ` desde 3,3 V, los tres Basic en JLCPCB (hasta el 2026-10-01 eran
2,49 kΩ y 16,0 kΩ, que pasaron a Extended). El divisor produce aproximadamente
2,425 V y el límite teórico es aproximadamente 1,01 A. `IPROPI` entregaría unos
1,2 V a 0,5 A y quedaría limitado cerca de 2,43 V, dentro del ADC de 3,3 V. Con
la ganancia de 1 000 µA/A, el firmware convierte con I ≈ V_IPROPI / 2,4 (0,417 A
por voltio). IMODE se
conecta a masa para regulación fixed-off-time con recuperación automática. PB5
mantiene `nSLEEP` a cero durante reset mediante R506; el firmware deberá retirar
`nSLEEP` inmediatamente al detectar `nFAULT`, ya que el modo elegido reintenta
automáticamente tras una sobrecorriente.

PF0 gobierna EN/PWM con TIM1_CH3N, la salida complementaria usada sola.
PC14 da la dirección, PB5 `nSLEEP`, PB6 lee `nFAULT` y PC0 (ADC12_IN6) mide
`IPROPI`. PC14 está en el dominio de respaldo: salida lenta (2 MHz como máximo) y
nunca como fuente de corriente; basta para una entrada lógica. V1/V2 de JP16 (rojo y azul) son `OUT1/OUT2`, como en la nota del manual, y
están en el extremo de J108 junto a JP21 (propietario, 2026-10-10). El motor es
de continua y el signo de DIR para cada sentido se fijará en el ensayo del
grupo. C503=100 nF entre VCP y VM y C504=22 nF
entre CPH y CPL siguen la aplicación de referencia de TI. C501=100 µF/35 V es un
bulk inicial, no un dimensionado cerrado. C502=100 nF es el bypass de VM; desde
el 2026-10-07 (issue #5) está a unos 5 mm del pin 11 y no a 11 mm, con su propia
vía de masa.

J112 exige 24 V DC aislados y limitados. Desde el 2026-10-07 (issue #6) entra
por su propio fusible F306 (prosemi 1206TD-2A) y un SS34, D308, antes de unirse
a `24V_ACT_RAW`, igual que J101 por F305/D307. Antes solo las ramas del grupo
(F303/D304) y de la válvula (F304/D305) bloqueaban la polaridad inversa: con el
cable invertido, −24 V llegaban a VIN y EN de U303 (mínimo absoluto −0,3 V) y
polarizaban en directo D701 y el diodo interno de Q701, con solo la limitación
de la fuente como protección. F306 lleva toda la placa en banco: el motor hasta
su ITRIP de 1 A, la válvula (0,42 A) y el buck de 12 V, unos 1,6 A en el peor
caso, así que es de 2 A y no de 1 A como F305. D308 cae unos 0,5 V a 1 A
(≈ 0,5 W en SMA). La fuente interna no pasa por ellos: PS701 se une por J121,
que se sigue abriendo antes de conectar una fuente en J112. La regla
`reverse-polarity` del modelo de placa recorre cada entrada de banco cableada a
mano y falla si un cable invertido alcanza algo más que el ánodo de un diodo
serie. No se ha añadido un TVS al rail de motor: su tensión de trabajo
y energía deben elegirse con la tolerancia y respuesta transitoria de la fuente
real para no superar los 40 V absolutos del DRV8876. El catálogo registra todas
las piezas como candidatas, no liberadas para compra. Se usa la huella estándar
con pad térmico de 3×3 mm, que baja al plano por cuatro vías; la matriz de vías y
el área de cobre que recomienda TI quedan por comprobar antes de fabricar.

### Telemetría de alimentación

R701/R702/R703/C701 y R704/R705/R706/C702 acondicionan `12V_PROTECTED` y
`24V_ACT_RAW`. Cada divisor tiene dos resistencias de 100 kΩ en serie y 10 kΩ a
masa, por lo que `Vin = 21 × Vadc`; a 12 V se esperan 0,571 V y a 24 V, 1,143 V.
La impedancia de Thévenin es 9,52 kΩ y el filtro de 100 nF produce una constante
de tiempo aproximada de 0,95 ms. El firmware usará tiempos de muestreo largos y
calibración con multímetro; estas entradas sirven para diagnóstico y brownout,
no como instrumento de precisión.

J114 es GND, 3,3 V, GND, 12 V protegidos, GND y 24 V de entrada (serigrafía
«G 3V3 G 12 G 24»). Se destina a osciloscopio/multímetro durante el banco; no se
debe alimentar la placa a través de sus pines. Desde el 2026-10-07 (issue #4)
cada raíl llega a su pin por 10 kΩ en 0603 (R723, R724 y R725, junto a la
cabecera) y nunca hay dos raíles contiguos. Antes iban directos y contiguos:
una punta que resbalara ponía 12 V en `3V3_CORE` (2↔3), 24 V en
`12V_PROTECTED` (3↔4) o 24 V en PF1 (4↔5). Ahora un resbalón solo lleva un raíl
a masa por 10 kΩ: 2,4 mA y 58 mW a 24 V, el 58 % de los 100 mW del 0603. Con un
multímetro de 10 MΩ el error es del 0,1 %. Con una sonda de unos 15 pF el polo
cae hacia 1 MHz, así que el rizado de los bucks se mide en sus condensadores y
no en J114. Las dos tensiones ADC salieron de la cabecera: se miden en C701 y
C702. La regla `probe-header` del modelo de placa lo comprueba.

### Driver de la electroválvula

La rama de válvula parte de `24V_ACT_RAW` pero dispone de F304=1 A y D305 propios.
U502 (UCC27517DBVR; pads DBV de TI SLUSAY4D: 1 VDD, 2 GND, 3 IN+, 4 IN−,
5 OUT) recibe PA7 mediante R511=33 Ω y R512=10 kΩ a masa; su salida
de 12 V conduce Q501 (SI2308A, 60 V) a través de R513=33 Ω, con R514=100 kΩ entre
puerta y source. C507=100 nF y C508=1 µF desacoplan el driver. D306 (SS34) queda
en paralelo con la bobina, cátodo a `24V_VALVE` y ánodo a `VALVE_RETURN`.

J113 usa HR A2506WV-05P vertical, LCSC `C382535`, girada 180° como en la
original: el pin 1 de JP3 (pad 5) a +24 V y el 2 (pad 4) al retorno conmutado;
el resto queda NC. La etapa se ha dibujado para probar la bobina
OLAB 6000BH/B0DN. Antes de liberarla deben medirse corriente en caliente, tiempo
de liberación, tensión de drenador y temperatura del MOSFET.

### Watchdog e interlock de actuadores

U601 (TPS3828-33DBVR) monitoriza `3V3_CORE` con umbral nominal de 2,93 V. Su
salida open-drain comparte `STM_NRST`; un timeout de WDI o una caída del rail
reinicia el STM32. PB4 llega por R601=33 Ω a U606 (SN74LVC1G132, NAND Schmitt),
que entrega WDI = NAND(`STM_NRST`, impulso): durante el reset WDI queda en alto y
quieto, porque el TPS3828 enclavaría RESET ante un pulso en WDI con RESET activo.
R602=1 kΩ a masa fija la entrada del impulso si el GPIO queda en alta impedancia.

`STM_NRST` sube por R101 contra C101, unos 0,5 ms/V, y las entradas del
SN74LVC2G08 sin histéresis piden 10 ns/V como mucho: U605 (SN74LVC1G17DBVR,
buffer Schmitt, con C605) entrega a las seis entradas de reset `STM_NRST_BUF`.
U602 (SN74LVC2G08DCTR) combina `STM_NRST_BUF` con `BREW_SLEEP_RAW` y
`VALVE_EN_RAW`. Si reset está activo, fuerza `BREW_SLEEP_INTERLOCK` y
`VALVE_EN_INTERLOCK` a cero independientemente del software. R603/R604 mantienen
las órdenes brutas a cero mientras el MCU arranca. U603 y U604, del mismo tipo,
hacen lo mismo con el armado del relé general (PB7) y las órdenes de calentador
(PC5), bomba (PB11) y molinillo (PC4); R722, R711, R713 y R717 son sus
pull-down. Ver el [diseño y temporización
del supervisor](../power/watchdog-interlock.md).

### Fuente integrada y corte general de cargas

PS701 es un Mean Well IRM-30-24 montado en la propia principal. F701 protege la
entrada completa, F702 separa la rama de la fuente y RV701 limita sobretensiones.
Desde el 2026-10-06 F701 y F702 son Littelfuse 215 de 1500 A a 250 VAC: F701
de 12 A, axial y soldado como el F1 original, y F702 de 2 A, como el F2 original, en pinzas
01110501Z, como F703 en el molinillo (issue #1, [corriente de
defecto supuesta](../power/power-architecture.md#corriente-de-defecto-supuesta-y-fusibles-de-red)).
Sigue abierta la energía del MOV. J121 se entrega puenteado para alimentar `24V_ACT_RAW`
desde PS701 y se abre antes de inyectar 24 V limitados por J112 durante el banco.

U303 (AP63301WU-7) convierte esos 24 V a `12V_ISO_RAW`. Hasta el 2026-10-08 era
un AP63200WU-7, sin stock en JLCPCB: el AP63301 es la versión de 3 A y PWM fijo
de la misma familia, con el mismo encapsulado, patillaje y referencia de 0,8 V.
Su límite de pico (4,5 A típicos, 4,9 A máximo) queda por debajo de los 6 A de
saturación de L302. La red de aplicación usa
10 µH, 10 µF/50 V en entrada (C310, 1210 desde el 2026-10-07: la curva de
Samsung da 4,8 µF a 24 V frente a 2,27 µF del 1206) más 100 nF de alta frecuencia en los pines
(C316, desde el 2026-10-07), dos condensadores de 22 µF/25 V en salida y divisor
330 kΩ/24 kΩ con 56 pF de avance. La tabla de 12 V del fabricante da 249 kΩ/18 kΩ
(11,87 V), pero 249 kΩ es Extended en JLCPCB; el par Basic 330/24 kΩ da
0,8 × (1 + 330/24) = 11,80 V según la ecuación 6 de la hoja, y el avance de 56 pF
queda dentro de los 10–220 pF que admite.

K701 es un relé Omron G5RL-1A-E-HR DC24 normalmente abierto (hasta el
2026-10-08, el -E-TV8, sin stock; Omron da a los dos el mismo plano y la misma
bobina). Sus dos pads COM y
sus dos pads NO se mantienen duplicados para repartir corriente. U603 exige a la
vez `STM_NRST` inactivo y `MAINS_ARM_RAW`; Q701 (BSS138LT1G, especificado a
VGS = 2,75 V, porque su puerta sale de los 3,3 V de U603) excita la bobina y D701
absorbe su energía. `LOAD_L_ENABLED` es la única fase que llega a los triacs de calentador,
bomba y molino. El dimensionado final depende aún de medir los motores y revisar
el calentador de 1900 W.

La selección del buck sigue la
[hoja de datos Diodes](https://www.diodes.com/datasheet/download/AP63200-AP63201-AP63203-AP63205.pdf)
(AP63203) y la del [AP63300/AP63301](https://www.lcsc.com/datasheet/C2158003.pdf)
y el corte del frontal la
[hoja de datos TI](https://www.ti.com/lit/pdf/slvsd76). Las referencias y su
instantánea de existencias están en el [catálogo de montaje](../assembly/parts-catalog.json).

## Validación reproducible

```
python3 tools/generate_controller_core.py
python3 tools/check_controller_core.py
python3 tools/validate_kicad.py
```

La cadena completa de la PCB está en [kicad-workflow.md](../kicad-workflow.md#cómo-continuar).

El comprobador propio lee el esquema y verifica alimentación, masas, conexión cruzada
UART, SWD, arranque, reserva PSRAM, enlace frontal y MPN/huella contra catálogo.
Es un parser limitado propio, no KiCad. Adicionalmente,
`python3 tools/validate_kicad.py` ejecuta ERC y coteja una netlist exportada por
KiCad. Las cabeceras de máquina deben probarse con los arneses antes de liberar
la mecánica. Ver [resultados y límites](../kicad-workflow.md). No hay firmware de
placa ni ensayo físico.

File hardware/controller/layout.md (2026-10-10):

# Colocación de la principal Rev A

Estado: colocación mecánica de conectores y colocación funcional con la
distribución de la placa original, dominio de red contiguo, reserva del disipador
y barrera red/SELV comprobada por DRC. Desde el 2026-09-23 la placa es de
cuatro capas y todas las redes están ruteadas a mano: DRC sin infracciones ni
conexiones abiertas. Tiene rellenos de masa en el lado SELV y serigrafía. Faltan
la comprobación 1:1 y la revisión de aislamiento. Aún no fabricable. La fuente
de verdad mecánica es `mechanical-source.json`; `tools/layout_controller_pcb.py`
consume sus coordenadas, coloca las 187 huellas eléctricas y comprueba que los
tres taladros aceptados no se muevan.

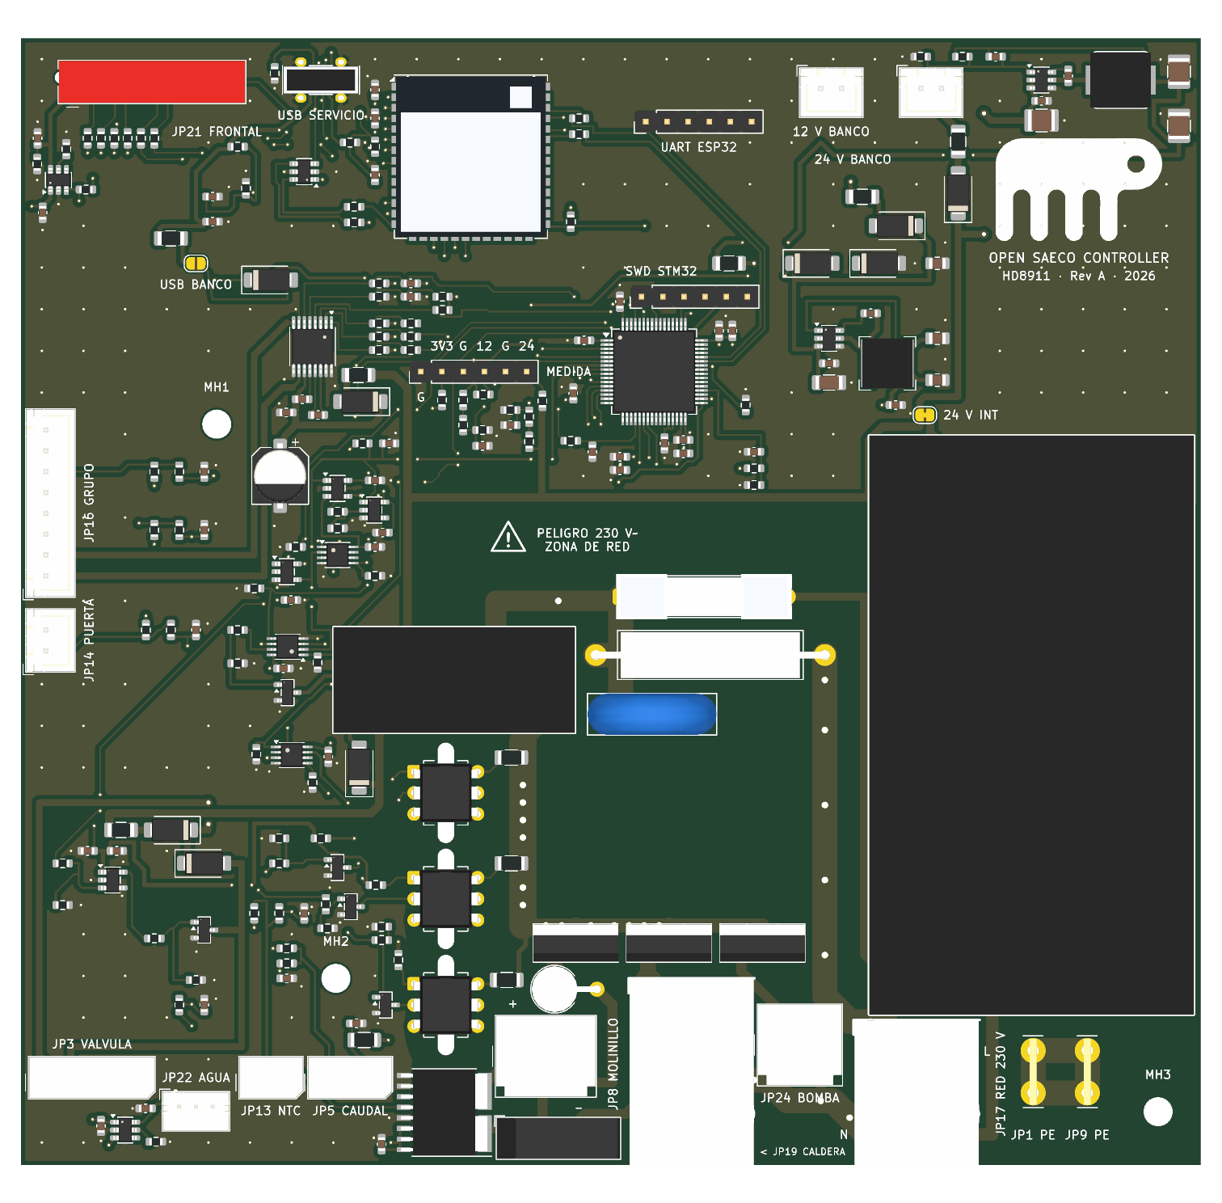
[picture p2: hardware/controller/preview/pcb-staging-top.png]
Vista superior de la colocación


Los cuerpos del relé, la IRM-30, el ESP32-S3-1U, los conectores de mazo y otras
piezas sin modelo en KiCad son [sustitutos simplificados](kicad/OpenSaeco.3dshapes/README.md):
la vista sirve para orientarse, no para medir alturas.

Mapa mecánico de conectores

## Sustitución física de la placa original

La posición de los mazos ya no se decide por conveniencia eléctrica. Se ha
rectificado IMG_1098 con el contorno aceptado de 141,6 × 135,2 mm y se ha usado
IMG_1101 para confirmar el sentido de entrada lateral. Se fija esta relación:

| Original | Rev A | Borde | Origen de huella X/Y (mm) | Giro |
|---|---|---|---:|---:|
| JP21 | J104, enlace del frontal nuevo | superior | 6,2 / 6,5 | 180° |
| JP16 | J108, grupo y micros | izquierdo | 3,0 / 64,5 | 90° |
| JP14 | J107, puerta/cajón | izquierdo | 3,0 / 73,5 | 90° |
| JP3 | J113, electroválvula | inferior | 3,5 / 125,3 | 0° |
| JP22 | J109, nivel de agua | inferior | 19,0 / 128,2 | 0° |
| JP13 | J105, NTC | inferior | 28,75 / 125,3 | 0° |
| JP5 | J106, caudalímetro | inferior | 37,0 / 125,3 | 0° |

Desde el 2026-10-06 J106 está 1,2 mm más al oeste y J105 0,25 mm, con el
acuerdo del propietario, para que U704 quepa en la barrera (ver «Corriente del
molinillo»). J106 queda a 1,5 mm de la foto, dentro de la incertidumbre.

La incertidumbre de posición asignada es ±1,5 mm. J104 ocupa la zona de JP21,
pero no reproduce su interfaz: desde el 2026-10-01 es el Würth WR-MM 690367181672
(ver «JP21: Würth WR-MM»), con pinout nuevo, y enlaza con la
nueva placa frontal. J110 queda inmediatamente a su derecha, accesible desde el
mismo borde superior para las pruebas por ordenador.

Todos los conectores de mazo entran en vertical (decisión del propietario,
2026-09-22). J101, J105–J109, J112–J113, J115, J117 y J118 pasan de las JST
S-series laterales a las B-series verticales. Los pads, el paso y el taladro eran
los mismos, así que las huellas conservaron origen y giro y el cobre no cambió.
Desde el 2026-09-29 J105, J106, J113, J115 y J117 llevan las cabeceras
identificadas por el propietario (ver «JP3, JP5, JP13, JP8 y JP24»).
J118 bajó entonces 0,8 mm para despejar PS701; desde el 2026-09-24 ya no es un
VH sino el TE 1971845-3 de tres vías (ver «JP17»). Los courtyards liberan unos 750 mm². La franja útil está
en x = 7–12,7 mm junto a J107/J108 y en y = 10–15,7 mm bajo J101/J112. En la fila
inferior se libera y ≈ 129–135 mm junto al borde. J110 (USB-C) también pasa a
vertical, con el HRO TYPE-C-31-D-06 (ver «USB»). J102–J104, J114, J116 y los
FASTON ya eran verticales.

JP8, JP19, JP24, JP17 y los dos FASTON de tierra son conectores obligatorios de
la principal completa, y ya tienen huella los seis. No son reservas para otra
placa: forman parte de esta misma PCB de sustitución.
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

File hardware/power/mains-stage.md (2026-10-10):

# Etapa de red y cargas — Rev A

Estado: en el esquema y en la PCB ruteada, con componentes candidatos. Todavía
no es apta para conectar a 230 V ni para pedir una placa montada.

## Lo que muestran las fotos de la original

La inspección de `docs/HD8911/photos/IMG_1085.HEIC` a `IMG_1089.HEIC` permite
identificar la topología general sin asumir valores que no se leen:
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

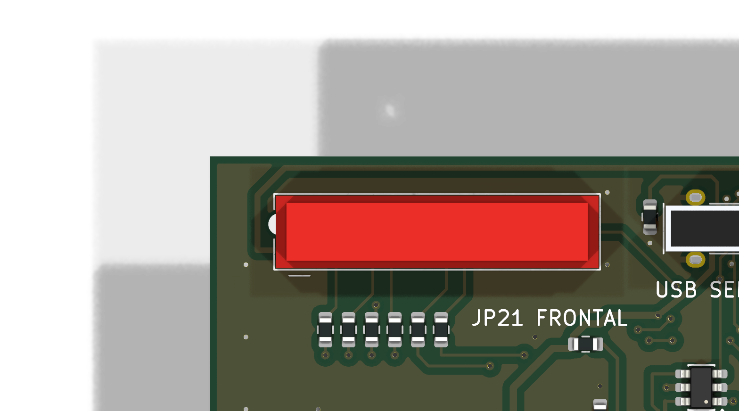
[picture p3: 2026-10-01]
hardware/controller/preview/j104-wr-mm-top.png

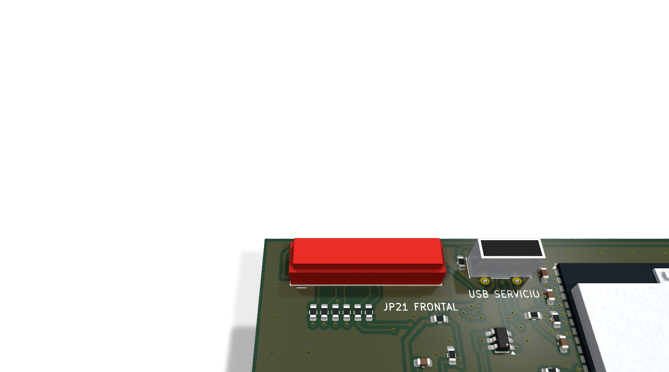
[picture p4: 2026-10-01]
hardware/controller/preview/j104-wr-mm-3d.png

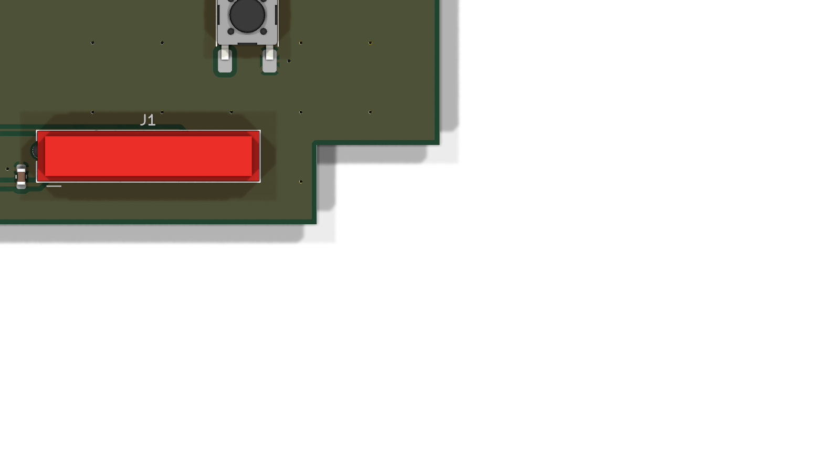
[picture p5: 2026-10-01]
hardware/front-panel/preview/j1-wr-mm-top.png

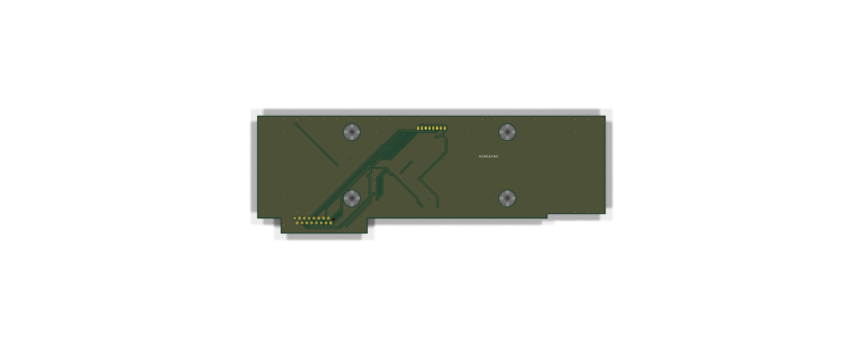
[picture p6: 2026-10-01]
hardware/front-panel/preview/pcb-bottom.png

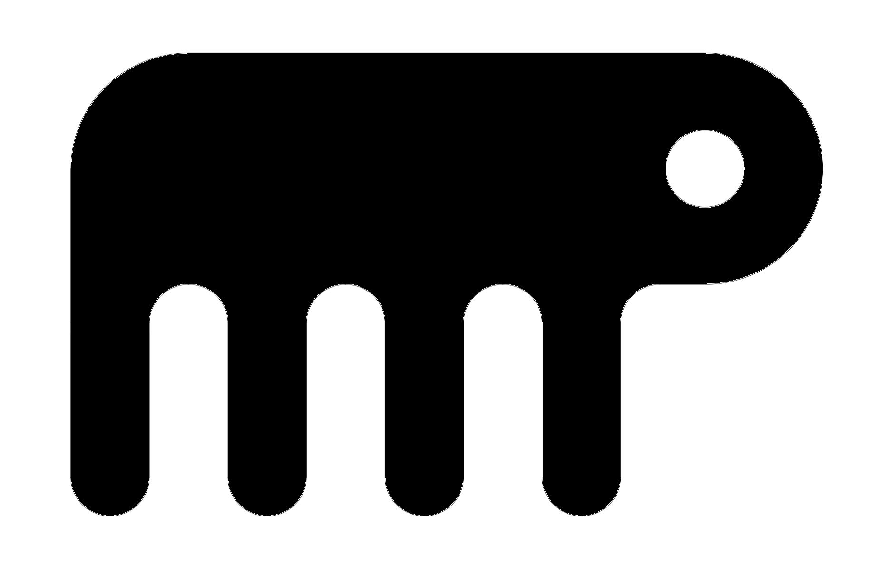
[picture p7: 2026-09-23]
hardware/controller/silkscreen/bicho.png

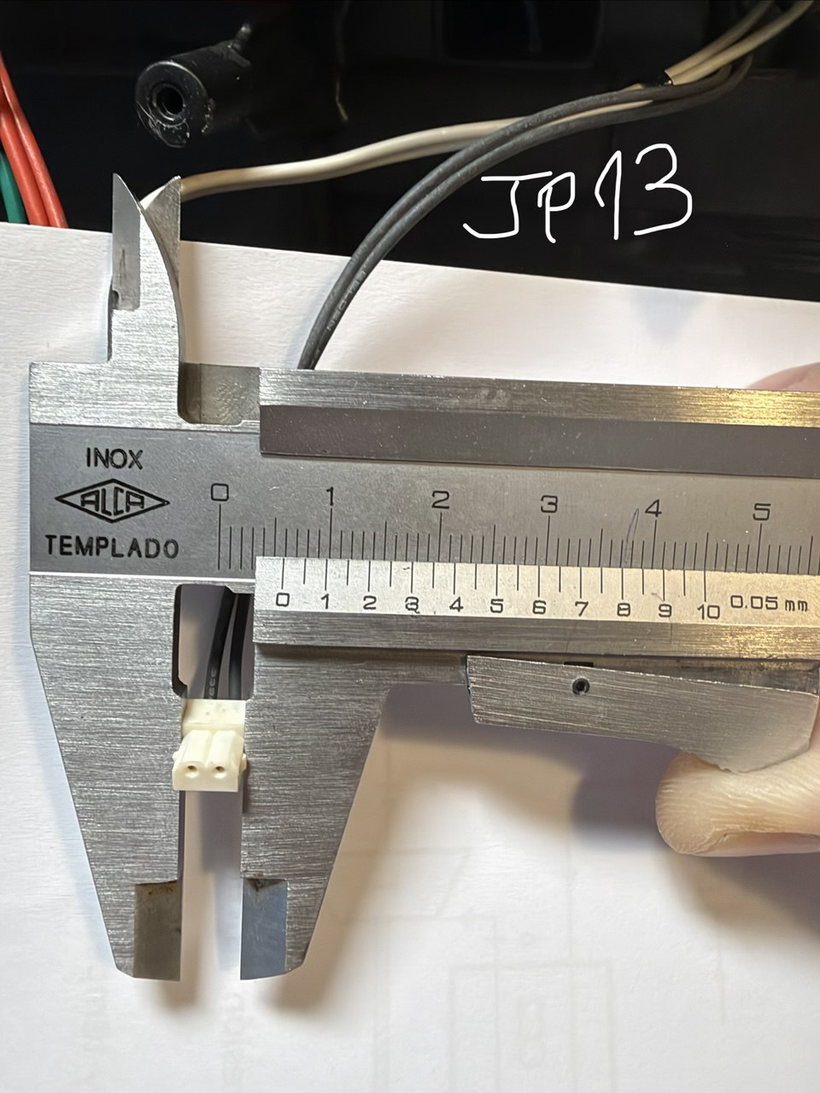
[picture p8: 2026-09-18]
docs/HD8911/photos/Conectores/JP13.jpg

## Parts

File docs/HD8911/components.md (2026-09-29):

# Componentes identificados y requisitos eléctricos

Consolidación del 2026-09-18 a partir de las referencias aportadas por el
propietario, el manual de servicio y el despiece local de la HD8911. Las cifras
derivadas se identifican como tales; no sustituyen los marcados de la unidad.

## Cargas

| Función | Referencia | Dato confirmado | Consecuencia para el diseño |
|---|---|---|---|
| Calentador XS4 | `421944028841` | 220–230 V AC, 1900 W; el manual especifica dos termostatos de un solo uso de 190 °C | Corriente nominal derivada: 8,26 A a 230 V y 8,64 A a 220 V. Requiere etapa y conectores de red, protección térmica independiente y dimensionado con margen |
| Bomba | `996530007753`, ULKA EP5/S GW | 220–230 V AC, 50 Hz, 48 W, 15 bar, servicio 2 min conectado / 1 min desconectado | Corriente nominal ideal derivada: 0,21 A a 230 V; la conmutación debe admitir la carga inductiva y sus transitorios |
| Electroválvula | `421944029371`; bobina OLAB `6000BH/B0DN` | 24 V DC/10 W; JP3.1 cuadrado a solenoide.1/+24 V, JP3.2 a solenoide.2/retorno; bobina 56,7 Ω; GND separado sin conectar; 0,073 V en modo diodo en ambos sentidos | Driver low-side con rueda libre externa. Derivación resistiva: 0,423 A y 10,16 W a 24 V, coherente con la especificación OLAB |
| Motor del grupo | `996530002796` / `11005214` | 24 V DC, reversible; devanado medido 54,7 Ω | Puente H con medida de corriente, frenado/estado seguro y margen para bloqueo. Límite resistivo derivado ≈0,439 A a 24 V; falta medir transitorio y variación con rotor/temperatura |
| Motor del molino V3.2 | `421944049151` | Conjunto 220–230 V; modo de servicio a 320 V DC; devanado medido 68 Ω | Continua rectificada de red. El límite resistivo parado sería ≈4,71 A a 320 V de pico (3,4 A eficaces), no corriente nominal. Rev A dimensiona la etapa a 3 A, casi el bloqueo; la marcha se mide en el prototipo |

El modo de servicio del manual separa expresamente las cargas: motor de grupo a
24 V DC; bomba a 230 V AC; electroválvula a 24 V DC; calentador a 230 V AC y
molino a 320 V DC. El valor de 320 V es coherente con rectificar 230 V RMS
(`230·√2 ≈ 325 V`), pero esta relación es una inferencia y no define por sí sola
la etapa de control.

La nota del propietario identifica un protector térmico de bomba de 100 °C. La
familia EP5 admite un alojamiento para protector y el conjunto tiene régimen 2/1,
pero no se ha encontrado una hoja primaria que vincule ese umbral exacto a esta
referencia; se conserva como dato por verificar en el marcado de la unidad.

## Caudalímetro JP5

La pieza de recambio `996530059843` / `NV99.099` se comercializa actualmente
asociada al marcado `932-9521-B`, correspondiente al **Digmesa FHKSC** con boquilla
de 1,2 mm y orientación 0°. El despiece local, sin embargo, imprime
`932-8521/00`; puede ser una revisión anterior o una errata y debe comprobarse el
marcado de la unidad antes de fijar la calibración. La
[hoja de datos del fabricante](https://digmesa.com/dam/jcr%3A51d2b47b-59a8-4c83-8b94-6bf1a980a2fc/932-952x-Bxxx_GB_20V_V04.pdf)
aporta:

- alimentación de 3,8 a 20 V DC y consumo inferior a 8 mA;
- salida NPN de colector abierto, 20 mA máximo, con pull-up externo;
- nivel bajo inferior a 0,7 V y fuga máxima de 10 µA;
- salida cuadrada con ciclo útil aproximado del 50 %;
- para `932-9521-B`: aproximadamente 1925 pulsos/litro, 0,07–0,56 l/min y
  0,42 bar de pérdida a caudal máximo;
- exactitud indicada ±2 % y repetibilidad mejor que ±0,25 %;
- instalación horizontal, contactos hacia arriba, en aspiración entre depósito
  y bomba; temperatura hasta 65 °C.

El valor nominal equivale a **0,519 ml/pulso**. Los 200 pulsos de reserva descritos
por Saeco representan unos **104 ml**. Digmesa exige calibrar pulsos/litro en el
conjunto real, por lo que 1925 es una constante inicial, no la calibración final.
El propio manual redondea la relación a unos 2000 pulsos/litro. El propietario
identificó la unidad física como `932-9521-B` y siguió el pad cuadrado para fijar
el orden eléctrico en vista cenital de la tarjeta: **pin 1 izquierdo = señal,
pin 2 = GND y pin 3 = VCC**.

La Rev A alimenta VCC desde `12V_PROTECTED`, dentro del intervalo admitido, y
eleva la salida de colector abierto a 3,3 V con 4,7 kΩ. Una resistencia serie de
1 kΩ y 10 nF protegen/filtran la entrada PA2/TIM2_CH3. Así el sensor trabaja a
12 V pero nunca aplica 12 V al GPIO.

## NTC JP13

El despiece identifica `996530073428`, sensor NTC UL de 550 mm. La tabla del
manual es la referencia de conversión. Un ajuste beta de todos sus puntos da,
como aproximación derivada, **R25 ≈ 49,9 kΩ y B ≈ 4037 K**; el error del ajuste
queda aproximadamente entre −1,1 % y +2,4 % frente a los valores nominales.
Para firmware conviene usar la tabla e interpolación, conservando sus tolerancias,
en vez de tratar el ajuste como especificación del fabricante.

Una resistencia de precisión de 4,7 kΩ a 3,3 V y el NTC a masa produciría
aproximadamente 3,07 V a 20 °C, 1,36 V a 100 °C y 0,53 V a 150 °C. También permite
diagnosticar cable abierto cerca de 3,3 V y cortocircuito cerca de 0 V. Son valores
para diseñar y simular; orientación, protección y umbrales deben cerrarse en el
esquema y ensayarse con el sensor real.

El control proporcional solicitado puede ser la primera implementación de banco,
pero el calentador debe quedar apagado ante NTC abierto/cortocircuitado, MCU sin
ejecución o pérdida de control. El termostato térmico externo no debe depender del
firmware.

El manual ya proporciona criterios funcionales: error 10 para NTC en corto,
error 11 para NTC abierto, error 14 al alcanzar 170 °C y error 15 si la máquina no
calienta. El calentamiento inicial se describe en unos 45 s. La temperatura medida
en taza debe quedar entre 69 y 85 °C para el primer producto y entre 72 y 85 °C
para el segundo; esos límites de taza no son el setpoint directo de la caldera.

## Grupo de infusión y autodosis

JP16 reúne el motor de grupo y dos microinterruptores. El manual indica que al
arrancar el motor busca el micro de reposo, invierte el sentido y se separa unos
1–2 mm. Por ello hacen falta control bidireccional y timeout incluso cuando el
contacto funciona.

El algoritmo de ajuste de dosis mide la corriente del **motor del grupo** durante
la compresión. Define una corriente base sin café `I0` entre 100 y 300 mA y
objetivos:

| Aroma | Objetivo del motor del grupo | Tiempo de molino |
|---|---:|---:|
| 1–2 | `I0 + 55 mA` | 3,0–8,1 s |
| 3 | `I0 + 100 mA` | 3,5–9,0 s |
| 4–5 | `I0 + 200 mA` | 4,0–10,0 s |

Esto lleva el punto de medida esperado hasta 500 mA, aunque no acota la corriente
de arranque o bloqueo. La primera etapa puede dimensionar el shunt para buena
resolución hasta aproximadamente 1 A y reservar margen mayor en el puente H; el
rating definitivo depende de medir bloqueo con una fuente limitada.

La lógica física es que una cantidad mayor de café opone más resistencia al
movimiento del pistón y eleva el par y la corriente del motor del grupo. `I0` se
actualiza durante un movimiento sin café, por ejemplo un aclarado, para descontar
rozamientos, temperatura y envejecimiento. El resultado corrige el **tiempo de
molido de los ciclos posteriores**; por eso el apartado aparece junto al molino.

La corriente del **motor del molino también se mide**, pero el manual le asigna
otra función: corriente anormalmente baja para detectar falta de grano y corriente
alta para detectar muelas bloqueadas. Por tanto, el diseño necesita dos medidas
distintas: una de baja tensión en el puente H del grupo para autodosis y otra en
el dominio de 320 V DC del molino para diagnóstico y protección.

El micro `996530073474` corresponde a la familia Zippy SM1. La
[familia SM1](https://www.zippy.com/es/04_switch_pro_page.aspx?ps_rfnbr=261)
declara hasta 300 mΩ iniciales y variantes de 0,1 a 16 A a 125/250 V AC, pero la
referencia Saeco no revela el sufijo eléctrico exacto. El arnés solo usa dos
terminales de cada contacto; queda por medir si son COM–NO o COM–NC.

## Puerta y nivel de agua

- La puerta/cajón usa `996530073209` / `12001890`, descrito como
  `MICROSWITCH XG/V3D`. No se ha localizado una hoja de datos primaria que una
  inequívocamente ese código Saeco con un rating y una configuración de contactos.
  JP14 usa dos hilos. La medida física confirma circuito abierto con puerta o
  cajón retirados y cerrado únicamente cuando ambos están colocados. La entrada
  activa a cero de la Rev A representa por tanto `DOOR_CLOSED_N`.
- El nivel de agua es el conjunto capacitivo V3 `421941306721`, con soporte
  `996530073436` y cable de tres polos `421946035161`. Está situado aproximadamente
  a un tercio de la altura del depósito. El cable observado usa rojo=VCC,
  blanco=señal y negro=GND; el propietario confirma alimentación válida a 3,3 o
  5 V. La Rev A elige 3,3 V y lleva la señal a PC3 (ADC12_IN9) mediante 1 kΩ/10 nF. Sigue
  pendiente medir si la salida es analógica, push-pull o colector abierto y sus
  niveles con depósito lleno/vacío.

## Datos que aún requieren la unidad física

1. Forma y niveles de salida del módulo capacitivo `421941306721` con depósito lleno/vacío.
2. COM–NO/COM–NC de los dos contactos de JP16.
3. Corrientes de arranque y bloqueo del motor de grupo y del molino.
4. Corriente en caliente de la electroválvula.
5. Referencia completa marcada en los microinterruptores e identificación de las carcasas de JP14, JP16 y JP22.

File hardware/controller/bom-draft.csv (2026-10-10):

reference | value | footprint | status | manufacturer | mpn | lcsc | jlc_class | pcba_type
U101 | STM32G431RBT6 | Package_QFP:LQFP-64_10x10mm_P0.5mm | candidate | STMicroelectronics | STM32G431RBT6 | C431633 | Extended | Economic and Standard
U201 | ESP32-S3-WROOM-1U-N8R8 | RF_Module:ESP32-S3-WROOM-1U | candidate | Espressif Systems | ESP32-S3-WROOM-1U-N8R8 | C2980300 | Extended | Standard Only
J101 | 12V_ISOLATED_INPUT / JST XH | Connector_JST:JST_XH_B2B-XH-A_1x02_P2.50mm_Vertical | candidate | JST | B2B-XH-A(LF)(SN) | C158012 | Extended | TBD
J102 | STM_SWD / 1x6 2.54mm | Connector_PinHeader_2.54mm:PinHeader_1x06_P2.54mm_Vertical | candidate | hanxia | HX PH254-01-06-Z-L11.5 through hole header | C52016393 | Extended | Economic and Standard
J103 | ESP_UART / 1x6 2.54mm | Connector_PinHeader_2.54mm:PinHeader_1x06_P2.54mm_Vertical | candidate | hanxia | HX PH254-01-06-Z-L11.5 through hole header | C52016393 | Extended | Economic and Standard
J104 | UI_LINK / WR-MM 16 | OpenSaeco:Wurth_WR-MM_690367181672_2x08_P1.27mm_Vertical | owner_identified_supply_pending | Wurth Elektronik | 690367181672 | C19103863 | Extended | TBD
R101 | 10k | Resistor_SMD:R_0603_1608Metric | candidate | UNI-ROYAL | 0603WAF1002T5E | C25804 | Basic | Economic and Standard
C101 | 100nF | Capacitor_SMD:C_0603_1608Metric | candidate | YAGEO | CC0603KRX7R9BB104 | C14663 | Basic | Economic and Standard
R102 | 10k | Resistor_SMD:R_0603_1608Metric | candidate | UNI-ROYAL | 0603WAF1002T5E | C25804 | Basic | Economic and Standard
R201 | 10k | Resistor_SMD:R_0603_1608Metric | candidate | UNI-ROYAL | 0603WAF1002T5E | C25804 | Basic | Economic and Standard
C201 | 1uF | Capacitor_SMD:C_0603_1608Metric | candidate | Samsung Electro-Mechanics | CL10A105KB8NNNC | C15849 | Basic | Economic and Standard
R202 | 10k | Resistor_SMD:R_0603_1608Metric | candidate | UNI-ROYAL | 0603WAF1002T5E | C25804 | Basic | Economic and Standard
R211 | 33 | Resistor_SMD:R_0603_1608Metric | candidate | UNI-ROYAL | 0603WAF330JT5E | C23140 | Basic | Economic and Standard
R212 | 33 | Resistor_SMD:R_0603_1608Metric | candidate | UNI-ROYAL | 0603WAF330JT5E | C23140 | Basic | Economic and Standard
R213 | 33 | Resistor_SMD:R_0603_1608Metric | candidate | UNI-ROYAL | 0603WAF330JT5E | C23140 | Basic | Economic and Standard
R214 | 33 | Resistor_SMD:R_0603_1608Metric | candidate | UNI-ROYAL | 0603WAF330JT5E | C23140 | Basic | Economic and Standard
R215 | 33 | Resistor_SMD:R_0603_1608Metric | candidate | UNI-ROYAL | 0603WAF330JT5E | C23140 | Basic | Economic and Standard
R216 | 33 | Resistor_SMD:R_0603_1608Metric | candidate | UNI-ROYAL | 0603WAF330JT5E | C23140 | Basic | Economic and Standard
R217 | 33 | Resistor_SMD:R_0603_1608Metric | candidate | UNI-ROYAL | 0603WAF330JT5E | C23140 | Basic | Economic and Standard
R218 | 33 | Resistor_SMD:R_0603_1608Metric | candidate | UNI-ROYAL | 0603WAF330JT5E | C23140 | Basic | Economic and Standard
C102 | 100nF / VDD16 | Capacitor_SMD:C_0603_1608Metric | candidate | YAGEO | CC0603KRX7R9BB104 | C14663 | Basic | Economic and Standard
C103 | 100nF / VDD32 | Capacitor_SMD:C_0603_1608Metric | candidate | YAGEO | CC0603KRX7R9BB104 | C14663 | Basic | Economic and Standard
C104 | 100nF / VDD48 | Capacitor_SMD:C_0603_1608Metric | candidate | YAGEO | CC0603KRX7R9BB104 | C14663 | Basic | Economic and Standard
C105 | 100nF / VDD64 | Capacitor_SMD:C_0603_1608Metric | candidate | YAGEO | CC0603KRX7R9BB104 | C14663 | Basic | Economic and Standard
C106 | 4.7uF / bulk STM | Capacitor_SMD:C_0603_1608Metric | candidate | Samsung Electro-Mechanics | CL10A475KO8NNNC | C19666 | Basic | Economic and Standard
C107 | 10nF / VDDA29 | Capacitor_SMD:C_0603_1608Metric | candidate | FH | 0603B103K500NT | C57112 | Basic | Economic and Standard
C108 | 1uF / VDDA29 | Capacitor_SMD:C_0603_1608Metric | candidate | Samsung Electro-Mechanics | CL10A105KB8NNNC | C15849 | Basic | Economic and Standard
C109 | 100nF / VREF28 | Capacitor_SMD:C_0603_1608Metric | candidate | YAGEO | CC0603KRX7R9BB104 | C14663 | Basic | Economic and Standard
C110 | 1uF / VREF28 | Capacitor_SMD:C_0603_1608Metric | candidate | Samsung Electro-Mechanics | CL10A105KB8NNNC | C15849 | Basic | Economic and Standard
C111 | 100nF / VBAT1 | Capacitor_SMD:C_0603_1608Metric | candidate | YAGEO | CC0603KRX7R9BB104 | C14663 | Basic | Economic and Standard
C202 | 100nF / ESP pad2 | Capacitor_SMD:C_0603_1608Metric | candidate | YAGEO | CC0603KRX7R9BB104 | C14663 | Basic | Economic and Standard
C203 | 10uF / ESP pad2 | Capacitor_SMD:C_0603_1608Metric | candidate | Samsung Electro-Mechanics | CL10A106MA8NRNC | C96446 | Basic | Economic and Standard
F301 | 1A / 72VDC | Fuse:Fuse_1206_3216Metric | candidate | prosemi | 1206TD-1A | C2838907 | Extended | Economic and Standard
D301 | SS34 | Diode_SMD:D_SMA | candidate | YONGYUTAI | SS34 | C2909963 | Extended | Economic and Standard
F305 | 1A / 72VDC bench | Fuse:Fuse_1206_3216Metric | candidate | prosemi | 1206TD-1A | C2838907 | Extended | Economic and Standard
D307 | SS34 / bench OR | Diode_SMD:D_SMA | candidate | YONGYUTAI | SS34 | C2909963 | Extended | Economic and Standard
D302 | SMAJ15A | Diode_SMD:D_SMA | candidate | Littelfuse | SMAJ15A | C148216 | Extended | TBD
C301 | 10uF / 25V input | Capacitor_SMD:C_0805_2012Metric | candidate | Samsung Electro-Mechanics | CL21A106KAYNNNE | C15850 | Basic | Economic and Standard
C302 | 100nF / input HF | Capacitor_SMD:C_0603_1608Metric | candidate | YAGEO | CC0603KRX7R9BB104 | C14663 | Basic | Economic and Standard
C315 | 10uF / 50V U301 VIN | Capacitor_SMD:C_1206_3216Metric | candidate | Samsung Electro-Mechanics | CL31B106KBHNNNE | C89632 | Extended | Economic and Standard
U301 | AP63203WU-7 | Package_TO_SOT_SMD:TSOT-23-6 | candidate | Diodes Incorporated | AP63203WU-7 | C780769 | Extended | Economic and Standard
C303 | 100nF / bootstrap | Capacitor_SMD:C_0603_1608Metric | candidate | YAGEO | CC0603KRX7R9BB104 | C14663 | Basic | Economic and Standard
L301 | 3.9uH | Inductor_SMD:L_Bourns-SRN6028 | candidate | Bourns | SRN6028C-3R9M | C19947652 | Extended | Economic and Standard
C304 | 22uF / 10V output | Capacitor_SMD:C_0805_2012Metric | candidate | CCTC | TCC0805X5R226M100FT | C380338 | Extended | Economic and Standard
C305 | 22uF / 10V output | Capacitor_SMD:C_0805_2012Metric | candidate | CCTC | TCC0805X5R226M100FT | C380338 | Extended | Economic and Standard
C306 | 100nF / output HF | Capacitor_SMD:C_0603_1608Metric | candidate | YAGEO | CC0603KRX7R9BB104 | C14663 | Basic | Economic and Standard
U302 | TPS2553DBVR / UI 0.5A limit | Package_TO_SOT_SMD:SOT-23-6 | candidate | Texas Instruments | TPS2553DBVR | C55266 | Extended | Economic and Standard
R301 | 100k | Resistor_SMD:R_0603_1608Metric | candidate | UNI-ROYAL | 0603WAF1003T5E | C25803 | Basic | Economic and Standard
R304 | 49.9k / UI ILIM 0.5A | Resistor_SMD:R_0603_1608Metric | candidate | UNI-ROYAL | 0603WAF4992T5E | C23184 | Basic | Economic and Standard
R305 | 1k / UI discharge | Resistor_SMD:R_0603_1608Metric | candidate | UNI-ROYAL | 0603WAF1001T5E | C21190 | Basic | Economic and Standard
C308 | 1uF / switch input | Capacitor_SMD:C_0603_1608Metric | candidate | Samsung Electro-Mechanics | CL10A105KB8NNNC | C15849 | Basic | Economic and Standard
C309 | 10uF / switch output | Capacitor_SMD:C_0603_1608Metric | candidate | Samsung Electro-Mechanics | CL10A106MA8NRNC | C96446 | Basic | Economic and Standard
J110 | USB-C SERVICE / USB 2.0 | OpenSaeco:USB_C_Receptacle_HRO_TYPE-C-31-D-06_Vertical | candidate | HRO ELECTRONICS | TYPE-C-31-D-06 | C2689964 | Extended | TBD
U203 | USBLC6-2SC6 | Package_TO_SOT_SMD:SOT-23-6 | candidate | STMicroelectronics | USBLC6-2SC6 | C7519 | Extended | Economic and Standard
R221 | 33 | Resistor_SMD:R_0603_1608Metric | candidate | UNI-ROYAL | 0603WAF330JT5E | C23140 | Basic | Economic and Standard
R222 | 33 | Resistor_SMD:R_0603_1608Metric | candidate | UNI-ROYAL | 0603WAF330JT5E | C23140 | Basic | Economic and Standard
R223 | 5.1k / CC1 Rd | Resistor_SMD:R_0603_1608Metric | candidate | UNI-ROYAL | 0603WAF5101T5E | C23186 | Basic | Economic and Standard
R224 | 5.1k / CC2 Rd | Resistor_SMD:R_0603_1608Metric | candidate | UNI-ROYAL | 0603WAF5101T5E | C23186 | Basic | Economic and Standard
R225 | 100k / VBUS sense top | Resistor_SMD:R_0603_1608Metric | candidate | UNI-ROYAL | 0603WAF1003T5E | C25803 | Basic | Economic and Standard
R226 | 100k / VBUS sense bottom | Resistor_SMD:R_0603_1608Metric | candidate | UNI-ROYAL | 0603WAF1003T5E | C25803 | Basic | Economic and Standard
C204 | 10nF / VBUS sense | Capacitor_SMD:C_0603_1608Metric | candidate | FH | 0603B103K500NT | C57112 | Basic | Economic and Standard
C205 | 1uF / USB VBUS | Capacitor_SMD:C_0603_1608Metric | candidate | Samsung Electro-Mechanics | CL10A105KB8NNNC | C15849 | Basic | Economic and Standard
F302 | 500mA resettable PTC | Fuse:Fuse_1206_3216Metric | candidate | Littelfuse | 1206L050YR | C163512 | Extended | TBD
J111 | USB BENCH POWER / OPEN | Jumper:SolderJumper-2_P1.3mm_Open_RoundedPad1.0x1.5mm | dnp_open_by_default
D303 | SS34 / USB power OR | Diode_SMD:D_SMA | candidate | YONGYUTAI | SS34 | C2909963 | Extended | Economic and Standard
J105 | JP13 NTC / 2 vías | OpenSaeco:HR_A2506WV-02P_1x02_P2.50mm_Vertical | owner_identified | HR(Joint Tech Elec) | A2506WV-02P | C382532 | Extended | TBD
R401 | 4.7k / NTC pull-up | Resistor_SMD:R_0603_1608Metric | candidate | UNI-ROYAL | 0603WAF4701T5E | C23162 | Basic | Economic and Standard
R402 | 1k / NTC serie | Resistor_SMD:R_0603_1608Metric | candidate | UNI-ROYAL | 0603WAF1001T5E | C21190 | Basic | Economic and Standard
C401 | 100nF / NTC filtro | Capacitor_SMD:C_0603_1608Metric | candidate | YAGEO | CC0603KRX7R9BB104 | C14663 | Basic | Economic and Standard
R413 | 390 / FLOW VCC limit | Resistor_SMD:R_1206_3216Metric | candidate | PANASONIC | ERJ-P08J391V | C2086379 | Extended | Economic and Standard
C408 | 100nF / FLOW VCC | Capacitor_SMD:C_0603_1608Metric | candidate | YAGEO | CC0603KRX7R9BB104 | C14663 | Basic | Economic and Standard
J106 | JP5 FLOW ADAPTER / VCC-GND-OC | OpenSaeco:HR_A2506WV-03P_1x03_P2.50mm_Vertical | owner_identified_owner_pinout | HR(Joint Tech Elec) | A2506WV-03P | C382533 | Extended | TBD
R403 | 4.7k / FLOW pull-up | Resistor_SMD:R_0603_1608Metric | candidate | UNI-ROYAL | 0603WAF4701T5E | C23162 | Basic | Economic and Standard
R404 | 1k / FLOW serie | Resistor_SMD:R_0603_1608Metric | candidate | UNI-ROYAL | 0603WAF1001T5E | C21190 | Basic | Economic and Standard
C402 | 10nF / FLOW filtro | Capacitor_SMD:C_0603_1608Metric | candidate | FH | 0603B103K500NT | C57112 | Basic | Economic and Standard
J107 | JP14 DOOR / A2506WV-02P | OpenSaeco:HR_A2506WV-02P_1x02_P2.50mm_Vertical | owner_identified | HR(Joint Tech Elec) | A2506WV-02P | C382532 | Extended | TBD
R405 | 10k / DOOR pull-up | Resistor_SMD:R_0603_1608Metric | candidate | UNI-ROYAL | 0603WAF1002T5E | C25804 | Basic | Economic and Standard
R406 | 1k / DOOR serie | Resistor_SMD:R_0603_1608Metric | candidate | UNI-ROYAL | 0603WAF1001T5E | C21190 | Basic | Economic and Standard
C403 | 100nF / DOOR filtro | Capacitor_SMD:C_0603_1608Metric | candidate | YAGEO | CC0603KRX7R9BB104 | C14663 | Basic | Economic and Standard
J108 | JP16 VISUAL V8..V1 / A2506WV-08P | OpenSaeco:HR_A2506WV-08P_1x08_P2.50mm_Vertical | owner_identified_supply_pending | HR(Joint Tech Elec) | A2506WV-08P | C476906 | Extended | TBD
R407 | 10k / PRES pull-up | Resistor_SMD:R_0603_1608Metric | candidate | UNI-ROYAL | 0603WAF1002T5E | C25804 | Basic | Economic and Standard
R408 | 1k / PRES serie | Resistor_SMD:R_0603_1608Metric | candidate | UNI-ROYAL | 0603WAF1001T5E | C21190 | Basic | Economic and Standard
C404 | 100nF / PRES filtro | Capacitor_SMD:C_0603_1608Metric | candidate | YAGEO | CC0603KRX7R9BB104 | C14663 | Basic | Economic and Standard
R409 | 10k / WORK pull-up | Resistor_SMD:R_0603_1608Metric | candidate | UNI-ROYAL | 0603WAF1002T5E | C25804 | Basic | Economic and Standard
R410 | 1k / WORK serie | Resistor_SMD:R_0603_1608Metric | candidate | UNI-ROYAL | 0603WAF1001T5E | C21190 | Basic | Economic and Standard
C405 | 100nF / WORK filtro | Capacitor_SMD:C_0603_1608Metric | candidate | YAGEO | CC0603KRX7R9BB104 | C14663 | Basic | Economic and Standard
U304 | TPS2553DBVR / JP22 0.13A limit | Package_TO_SOT_SMD:SOT-23-6 | candidate | Texas Instruments | TPS2553DBVR | C55266 | Extended | Economic and Standard
R306 | 210k / JP22 ILIM 0.13A | Resistor_SMD:R_0603_1608Metric | candidate | UNI-ROYAL | 0603WAF2103T5E | C22952 | Extended | Economic and Standard
C409 | 100nF / JP22 switch input | Capacitor_SMD:C_0603_1608Metric | candidate | YAGEO | CC0603KRX7R9BB104 | C14663 | Basic | Economic and Standard
C410 | 1uF / JP22 VCC | Capacitor_SMD:C_0603_1608Metric | candidate | Samsung Electro-Mechanics | CL10A105KB8NNNC | C15849 | Basic | Economic and Standard
J109 | JP22 WATER / RED-WHITE-BLACK | Connector_JST:JST_ZH_B3B-ZR_1x03_P1.50mm_Vertical | owner_identified_owner_pinout | JST | B3B-ZR(LF)(SN) | C158001 | Extended | TBD
R411 | 1k / WATER serie | Resistor_SMD:R_0603_1608Metric | candidate | UNI-ROYAL | 0603WAF1001T5E | C21190 | Basic | Economic and Standard
R415 | 100k / WATER pull-up DNP | Resistor_SMD:R_0603_1608Metric | dnp_value_after_wl01 | UNI-ROYAL | 0603WAF1003T5E | C25803 | Basic | Economic and Standard
R416 | 100k / WATER pull-down DNP | Resistor_SMD:R_0603_1608Metric | dnp_value_after_wl01 | UNI-ROYAL | 0603WAF1003T5E | C25803 | Basic | Economic and Standard
C406 | 10nF / WATER filtro | Capacitor_SMD:C_0603_1608Metric | candidate | FH | 0603B103K500NT | C57112 | Basic | Economic and Standard
R412 | 1k / GRINDER I serie | Resistor_SMD:R_0603_1608Metric | candidate | UNI-ROYAL | 0603WAF1001T5E | C21190 | Basic | Economic and Standard
C407 | 100nF / GRINDER I filtro | Capacitor_SMD:C_0603_1608Metric | candidate | YAGEO | CC0603KRX7R9BB104 | C14663 | Basic | Economic and Standard
J112 | 24V_ACTUATOR_INPUT / JST XH | Connector_JST:JST_XH_B2B-XH-A_1x02_P2.50mm_Vertical | candidate | JST | B2B-XH-A(LF)(SN) | C158012 | Extended | TBD
F306 | 2A / 72VDC bench | Fuse:Fuse_1206_3216Metric | candidate | prosemi | 1206TD-2A | C2838912 | Extended | Economic and Standard
D308 | SS34 / bench polarity | Diode_SMD:D_SMA | candidate | YONGYUTAI | SS34 | C2909963 | Extended | Economic and Standard
F303 | 1A / 72VDC | Fuse:Fuse_1206_3216Metric | candidate | prosemi | 1206TD-1A | C2838907 | Extended | Economic and Standard
D304 | SS34 | Diode_SMD:D_SMA | candidate | YONGYUTAI | SS34 | C2909963 | Extended | Economic and Standard
C501 | 100uF / 35V motor bulk | Capacitor_SMD:CP_Elec_6.3x7.7 | candidate | Lelon | VZH101M1VTR-0607 | C176683 | Extended | Economic and Standard
C502 | 100nF / VM local | Capacitor_SMD:C_0603_1608Metric | candidate | YAGEO | CC0603KRX7R9BB104 | C14663 | Basic | Economic and Standard
U501 | DRV8876PWPR | Package_SO:HTSSOP-16-1EP_4.4x5mm_P0.65mm_EP3x3mm | candidate | Texas Instruments | DRV8876PWPR | C575551 | Extended | TBD
C503 | 100nF / VCP-VM | Capacitor_SMD:C_0603_1608Metric | candidate | YAGEO | CC0603KRX7R9BB104 | C14663 | Basic | Economic and Standard
C504 | 22nF / CPH-CPL | Capacitor_SMD:C_0603_1608Metric | candidate | FH | 0603B223K500NT | C77571 | Extended | Economic and Standard
R501 | 33 / EN | Resistor_SMD:R_0603_1608Metric | candidate | UNI-ROYAL | 0603WAF330JT5E | C23140 | Basic | Economic and Standard
R502 | 10k / EN pull-down | Resistor_SMD:R_0603_1608Metric | candidate | UNI-ROYAL | 0603WAF1002T5E | C25804 | Basic | Economic and Standard
R503 | 33 / PH | Resistor_SMD:R_0603_1608Metric | candidate | UNI-ROYAL | 0603WAF330JT5E | C23140 | Basic | Economic and Standard
R504 | 10k / PH pull-down | Resistor_SMD:R_0603_1608Metric | candidate | UNI-ROYAL | 0603WAF1002T5E | C25804 | Basic | Economic and Standard
R505 | 33 / nSLEEP | Resistor_SMD:R_0603_1608Metric | candidate | UNI-ROYAL | 0603WAF330JT5E | C23140 | Basic | Economic and Standard
R506 | 10k / nSLEEP pull-down | Resistor_SMD:R_0603_1608Metric | candidate | UNI-ROYAL | 0603WAF1002T5E | C25804 | Basic | Economic and Standard
R507 | 10k / nFAULT pull-up | Resistor_SMD:R_0603_1608Metric | candidate | UNI-ROYAL | 0603WAF1002T5E | C25804 | Basic | Economic and Standard
R508 | 18k / VREF top | Resistor_SMD:R_0603_1608Metric | candidate | UNI-ROYAL | 0603WAF1802T5E | C25810 | Basic | TBD
R509 | 49.9k / VREF bottom | Resistor_SMD:R_0603_1608Metric | candidate | UNI-ROYAL | 0603WAF4992T5E | C23184 | Basic | Economic and Standard
C505 | 100nF / VREF | Capacitor_SMD:C_0603_1608Metric | candidate | YAGEO | CC0603KRX7R9BB104 | C14663 | Basic | Economic and Standard
R510 | 2.4k / IPROPI | Resistor_SMD:R_0603_1608Metric | candidate | UNI-ROYAL | 0603WAF2401T5E | C22940 | Basic | Economic and Standard
C506 | 10nF / IPROPI | Capacitor_SMD:C_0603_1608Metric | candidate | FH | 0603B103K500NT | C57112 | Basic | Economic and Standard
J113 | JP3 VALVE / A2506 | OpenSaeco:HR_A2506WV-05P_1x05_P2.50mm_Vertical | owner_identified_owner_pinout | HR(Joint Tech Elec) | A2506WV-05P | C382535 | Extended | TBD
F304 | 1A / 72VDC | Fuse:Fuse_1206_3216Metric | candidate | prosemi | 1206TD-1A | C2838907 | Extended | Economic and Standard
D305 | SS34 | Diode_SMD:D_SMA | candidate | YONGYUTAI | SS34 | C2909963 | Extended | Economic and Standard
D306 | SS34 / flyback | Diode_SMD:D_SMA | candidate | YONGYUTAI | SS34 | C2909963 | Extended | Economic and Standard
U502 | UCC27517DBVR | Package_TO_SOT_SMD:SOT-23-5 | candidate | Texas Instruments | UCC27517DBVR | C99395 | Extended | TBD
Q501 | SI2308A | Package_TO_SOT_SMD:SOT-23 | candidate | UMW | SI2308A | C347491 | Extended | TBD
R511 | 33 / IN | Resistor_SMD:R_0603_1608Metric | candidate | UNI-ROYAL | 0603WAF330JT5E | C23140 | Basic | Economic and Standard
R512 | 10k / IN pull-down | Resistor_SMD:R_0603_1608Metric | candidate | UNI-ROYAL | 0603WAF1002T5E | C25804 | Basic | Economic and Standard
R513 | 33 / gate | Resistor_SMD:R_0603_1608Metric | candidate | UNI-ROYAL | 0603WAF330JT5E | C23140 | Basic | Economic and Standard
R514 | 100k / gate pull-down | Resistor_SMD:R_0603_1608Metric | candidate | UNI-ROYAL | 0603WAF1003T5E | C25803 | Basic | Economic and Standard
C507 | 100nF / driver local | Capacitor_SMD:C_0603_1608Metric | candidate | YAGEO | CC0603KRX7R9BB104 | C14663 | Basic | Economic and Standard
C508 | 1uF / driver local | Capacitor_SMD:C_0603_1608Metric | candidate | Samsung Electro-Mechanics | CL10A105KB8NNNC | C15849 | Basic | Economic and Standard
U601 | TPS3828-33DBVR | Package_TO_SOT_SMD:SOT-23-5 | candidate | Texas Instruments | TPS3828-33DBVR | C20032 | Extended | TBD
U602 | SN74LVC2G08DCTR | Package_SO:SSOP-8_2.95x2.8mm_P0.65mm | candidate | Texas Instruments | SN74LVC2G08DCTR | C352973 | Extended | TBD
R601 | 33 / WDI | Resistor_SMD:R_0603_1608Metric | candidate | UNI-ROYAL | 0603WAF330JT5E | C23140 | Basic | Economic and Standard
R602 | 1k / kick pull-down | Resistor_SMD:R_0603_1608Metric | candidate | UNI-ROYAL | 0603WAF1001T5E | C21190 | Basic | Economic and Standard
R603 | 10k / brew arm pull-down | Resistor_SMD:R_0603_1608Metric | candidate | UNI-ROYAL | 0603WAF1002T5E | C25804 | Basic | Economic and Standard
R604 | 10k / valve pull-down | Resistor_SMD:R_0603_1608Metric | candidate | UNI-ROYAL | 0603WAF1002T5E | C25804 | Basic | Economic and Standard
C601 | 100nF / supervisor local | Capacitor_SMD:C_0603_1608Metric | candidate | YAGEO | CC0603KRX7R9BB104 | C14663 | Basic | Economic and Standard
C602 | 100nF / logic local | Capacitor_SMD:C_0603_1608Metric | candidate | YAGEO | CC0603KRX7R9BB104 | C14663 | Basic | Economic and Standard
U605 | SN74LVC1G17DBVR | Package_TO_SOT_SMD:SOT-23-5 | candidate | Texas Instruments | SN74LVC1G17DBVR | C7836 | Extended | TBD
C605 | 100nF / reset buffer local | Capacitor_SMD:C_0603_1608Metric | candidate | YAGEO | CC0603KRX7R9BB104 | C14663 | Basic | Economic and Standard
U606 | SN74LVC1G132DBVR | Package_TO_SOT_SMD:SOT-23-5 | candidate | Texas Instruments | SN74LVC1G132DBVR | C403723 | Extended | TBD
C606 | 100nF / WDI gate local | Capacitor_SMD:C_0603_1608Metric | candidate | YAGEO | CC0603KRX7R9BB104 | C14663 | Basic | Economic and Standard
R701 | 100k / 12V div A | Resistor_SMD:R_0603_1608Metric | candidate | UNI-ROYAL | 0603WAF1003T5E | C25803 | Basic | Economic and Standard
R702 | 100k / 12V div B | Resistor_SMD:R_0603_1608Metric | candidate | UNI-ROYAL | 0603WAF1003T5E | C25803 | Basic | Economic and Standard
R703 | 10k / 12V div low | Resistor_SMD:R_0603_1608Metric | candidate | UNI-ROYAL | 0603WAF1002T5E | C25804 | Basic | Economic and Standard
C701 | 100nF / 12V ADC | Capacitor_SMD:C_0603_1608Metric | candidate | YAGEO | CC0603KRX7R9BB104 | C14663 | Basic | Economic and Standard
R704 | 100k / 24V div A | Resistor_SMD:R_0603_1608Metric | candidate | UNI-ROYAL | 0603WAF1003T5E | C25803 | Basic | Economic and Standard
R705 | 100k / 24V div B | Resistor_SMD:R_0603_1608Metric | candidate | UNI-ROYAL | 0603WAF1003T5E | C25803 | Basic | Economic and Standard
R706 | 10k / 24V div low | Resistor_SMD:R_0603_1608Metric | candidate | UNI-ROYAL | 0603WAF1002T5E | C25804 | Basic | Economic and Standard
C702 | 100nF / 24V ADC | Capacitor_SMD:C_0603_1608Metric | candidate | YAGEO | CC0603KRX7R9BB104 | C14663 | Basic | Economic and Standard
R723 | 10k / J114 3V3 probe | Resistor_SMD:R_0603_1608Metric | candidate | UNI-ROYAL | 0603WAF1002T5E | C25804 | Basic | Economic and Standard
R724 | 10k / J114 12V probe | Resistor_SMD:R_0603_1608Metric | candidate | UNI-ROYAL | 0603WAF1002T5E | C25804 | Basic | Economic and Standard
R725 | 10k / J114 24V probe | Resistor_SMD:R_0603_1608Metric | candidate | UNI-ROYAL | 0603WAF1002T5E | C25804 | Basic | Economic and Standard
J114 | POWER PROBE / MEASURE ONLY | Connector_PinHeader_2.54mm:PinHeader_1x06_P2.54mm_Vertical | candidate | hanxia | HX PH254-01-06-Z-L11.5 through hole header | C52016393 | Extended | Economic and Standard
RT701 | 10k B3380 / heatsink air | Resistor_SMD:R_0603_1608Metric | candidate | Murata Electronics | NCP18XH103F03RB | C13564 | Extended | Economic and Standard
R726 | 10k / heatsink NTC pull-up | Resistor_SMD:R_0603_1608Metric | candidate | UNI-ROYAL | 0603WAF1002T5E | C25804 | Basic | Economic and Standard
C704 | 100nF / heatsink NTC | Capacitor_SMD:C_0603_1608Metric | candidate | YAGEO | CC0603KRX7R9BB104 | C14663 | Basic | Economic and Standard
J115 | JP8 GRINDER / 320VDC | OpenSaeco:LEOCO_3941P03_1x03_P3.96mm_Vertical | owner_identified_not_stocked_by_jlcpcb | LEOCO | 3941P03*000 |  |  | hand_solder_or_consigned
C708 | Motor suppression C / JP8, DNP until EMI test | Capacitor_SMD:C_2220_5750Metric | dnp_after_emission_measurement
J116 | JP19 HEATER / 1900W 27R5 | OpenSaeco:TE_RAST5_1971845-4_1x04_P5.00mm_Vertical | owner_identified | TE Connectivity | 1971845-4 | C2149727 | Extended | Standard
J117 | JP24 PUMP / 230VAC | OpenSaeco:LEOCO_5001P02_1x02_P5.00mm_Vertical | owner_identified_not_stocked_by_jlcpcb | LEOCO | 5001P020013 |  |  | hand_solder_or_consigned
J118 | JP17 MAINS / L-N | OpenSaeco:TE_RAST5_1971845-3_1x03_P5.00mm_Vertical | owner_identified | TE Connectivity | 1971845-3 | C5169636 | Extended | TBD
J119 | JP1 PE TO BOILER | OpenSaeco:TE_FASTON_63824-1_Tab_6.35mm_Vertical | candidate | TE Connectivity | 63824-1 | C575074 | Extended | TBD
J120 | JP9 PE INPUT | OpenSaeco:TE_FASTON_63824-1_Tab_6.35mm_Vertical | candidate | TE Connectivity | 63824-1 | C575074 | Extended | TBD
F701 | T12AH / 250V MAIN | OpenSaeco:Fuse_Littelfuse_0215_5x20mm_Axial_Horizontal_P27.50mm | candidate | Littelfuse | 0215012.MXEP | C142789 | Extended | Economic and Standard
RV701 | S14K275 / 275VAC MOV | Varistor:RV_Disc_D15.5mm_W5mm_P7.5mm | candidate | TDK | B72214S0271K101 | C7502584 | Extended | Economic and Standard
C707 | 56nF X2 / mains input | Capacitor_SMD:C_2220_5750Metric | candidate | Murata Electronics | GA355XR7GB563KW06L | C161105 | Extended | Economic and Standard
F702 | T2AH / PSU | Fuse:Fuseholder_Clip-5x20mm_Littelfuse_111_Inline_P20.00x5.00mm_D1.05mm_Horizontal | candidate | Littelfuse | 0215002.MXP | C142716 | Extended | Economic and Standard
PS701 | IRM-30-24 | OpenSaeco:MeanWell_IRM-30_THT | candidate_pending_motor_current_validation | MEAN WELL | IRM-30-24 | C6280124 | Extended | Economic and Standard
J121 | 24V INTERNAL SELECT / OPEN FOR BENCH | Jumper:SolderJumper-2_P1.3mm_Bridged_RoundedPad1.0x1.5mm | normally_closed_open_for_external_24V
U303 | AP63301WU-7 / 24V to 12V | Package_TO_SOT_SMD:TSOT-23-6 | candidate | Diodes Incorporated | AP63301WU-7 | C2158003 | Extended | TBD
L302 | 10uH / 3.5A | Inductor_SMD:L_Bourns_SRP7028A_7.3x6.6mm | candidate | Bourns | SRP7028A-100M | C2687402 | Extended | TBD
C310 | 10uF / 50V input 1210 | Capacitor_SMD:C_1210_3225Metric | candidate | Samsung Electro-Mechanics | CL32B106KBJNNNE | C138687 | Extended | Economic and Standard
C316 | 100nF / U303 VIN HF | Capacitor_SMD:C_0603_1608Metric | candidate | YAGEO | CC0603KRX7R9BB104 | C14663 | Basic | Economic and Standard
C311 | 22uF / 25V output A | Capacitor_SMD:C_1210_3225Metric | candidate | CCTC | TCC1210X7R226K250MT | C49118556 | Extended | Economic and Standard
C312 | 22uF / 25V output B | Capacitor_SMD:C_1210_3225Metric | candidate | CCTC | TCC1210X7R226K250MT | C49118556 | Extended | Economic and Standard
C313 | 100nF / BST | Capacitor_SMD:C_0603_1608Metric | candidate | YAGEO | CC0603KRX7R9BB104 | C14663 | Basic | Economic and Standard
R302 | 330k / 12V FB high | Resistor_SMD:R_0603_1608Metric | candidate | UNI-ROYAL | 0603WAF3303T5E | C23137 | Basic | Economic and Standard
R303 | 24k / 12V FB low | Resistor_SMD:R_0603_1608Metric | candidate | UNI-ROYAL | 0603WAF2402T5E | C23352 | Basic | Economic and Standard
C314 | 56pF / feed-forward | Capacitor_SMD:C_0603_1608Metric | candidate | AIDE CAPACITOR | 0603C0G560J500NT | C49326334 | Extended | Economic and Standard
U603 | SN74LVC2G08DCTR | Package_SO:SSOP-8_2.95x2.8mm_P0.65mm | candidate | Texas Instruments | SN74LVC2G08DCTR | C352973 | Extended | TBD
Q701 | BSS138LT1G / relay coil | Package_TO_SOT_SMD:SOT-23 | candidate | onsemi | BSS138LT1G | C82045 | Extended | TBD
C603 | 100nF / arm gate local | Capacitor_SMD:C_0603_1608Metric | candidate | YAGEO | CC0603KRX7R9BB104 | C14663 | Basic | Economic and Standard
R722 | 10k / mains arm pull-down | Resistor_SMD:R_0603_1608Metric | candidate | UNI-ROYAL | 0603WAF1002T5E | C25804 | Basic | Economic and Standard
R801 | 33 / relay gate | Resistor_SMD:R_0603_1608Metric | candidate | UNI-ROYAL | 0603WAF330JT5E | C23140 | Basic | Economic and Standard
R802 | 100k / relay off | Resistor_SMD:R_0603_1608Metric | candidate | UNI-ROYAL | 0603WAF1003T5E | C25803 | Basic | Economic and Standard
D701 | SS34 / relay flyback | Diode_SMD:D_SMA | candidate | YONGYUTAI | SS34 | C2909963 | Extended | Economic and Standard
K701 | G5RL-1A-E-HR DC24 | OpenSaeco:Relay_SPST_Omron_G5RL-1A-E-TV8 | candidate_not_released | Omron Electronics | G5RL-1A-E-HR DC24 | C397236 | Extended | Economic and Standard
R711 | 10k / heater arm pull-down | Resistor_SMD:R_0603_1608Metric | candidate | UNI-ROYAL | 0603WAF1002T5E | C25804 | Basic | Economic and Standard
R707 | 33 / opto LED gate | Resistor_SMD:R_0603_1608Metric | candidate | UNI-ROYAL | 0603WAF330JT5E | C23140 | Basic | Economic and Standard
R708 | 100k / opto LED off | Resistor_SMD:R_0603_1608Metric | candidate | UNI-ROYAL | 0603WAF1003T5E | C25803 | Basic | Economic and Standard
Q705 | BSS138LT1G / heater opto LED | Package_TO_SOT_SMD:SOT-23 | candidate | onsemi | BSS138LT1G | C82045 | Extended | TBD
R709 | 1k / opto LED series | Resistor_SMD:R_0603_1608Metric | candidate | ROHM Semicon | ESR03EZPF1001 | C2653986 | Extended | TBD
U701 | MOC3083 / zero-cross | OpenSaeco:DIP-6_W7.62mm_BarrierSlot | candidate | Lite-On | MOC3083 | C10797 | Extended | Economic and Standard
R710 | 390 / gate limit 500V | Resistor_SMD:R_1206_3216Metric | candidate | PANASONIC | ERJ-P08J391V | C2086379 | Extended | Economic and Standard
Q703 | BTA24-800BWRG / heater | Package_TO_SOT_THT:TO-220-3_Vertical | candidate | STMicroelectronics | BTA24-800BWRG | C15293 | Extended | Economic and Standard
R713 | 10k / pump arm pull-down | Resistor_SMD:R_0603_1608Metric | candidate | UNI-ROYAL | 0603WAF1002T5E | C25804 | Basic | Economic and Standard
U604 | SN74LVC2G08DCTR | Package_SO:SSOP-8_2.95x2.8mm_P0.65mm | candidate | Texas Instruments | SN74LVC2G08DCTR | C352973 | Extended | TBD
C604 | 100nF / pump gate local | Capacitor_SMD:C_0603_1608Metric | candidate | YAGEO | CC0603KRX7R9BB104 | C14663 | Basic | Economic and Standard
R714 | 33 / opto LED gate | Resistor_SMD:R_0603_1608Metric | candidate | UNI-ROYAL | 0603WAF330JT5E | C23140 | Basic | Economic and Standard
R715 | 100k / opto LED off | Resistor_SMD:R_0603_1608Metric | candidate | UNI-ROYAL | 0603WAF1003T5E | C25803 | Basic | Economic and Standard
Q706 | BSS138LT1G / pump opto LED | Package_TO_SOT_SMD:SOT-23 | candidate | onsemi | BSS138LT1G | C82045 | Extended | TBD
R716 | 1k / opto LED series | Resistor_SMD:R_0603_1608Metric | candidate | ROHM Semicon | ESR03EZPF1001 | C2653986 | Extended | TBD
U702 | MOC3083 / zero-cross | OpenSaeco:DIP-6_W7.62mm_BarrierSlot | candidate | Lite-On | MOC3083 | C10797 | Extended | Economic and Standard
R712 | 390 / gate limit 500V | Resistor_SMD:R_1206_3216Metric | candidate | PANASONIC | ERJ-P08J391V | C2086379 | Extended | Economic and Standard
Q704 | BTA24-800BWRG / pump | Package_TO_SOT_THT:TO-220-3_Vertical | candidate | STMicroelectronics | BTA24-800BWRG | C15293 | Extended | Economic and Standard
C705 | RC snubber C / Q704, DNP until PU-03 | Capacitor_SMD:C_1812_4532Metric | dnp_after_dvdt_measurement
R727 | RC snubber R / Q704, DNP until PU-03 | Resistor_SMD:R_2512_6332Metric | dnp_after_dvdt_measurement
R717 | 10k / grinder arm pull-down | Resistor_SMD:R_0603_1608Metric | candidate | UNI-ROYAL | 0603WAF1002T5E | C25804 | Basic | Economic and Standard
R718 | 33 / opto LED gate | Resistor_SMD:R_0603_1608Metric | candidate | UNI-ROYAL | 0603WAF330JT5E | C23140 | Basic | Economic and Standard
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

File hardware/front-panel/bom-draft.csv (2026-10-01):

reference | value | footprint | status | manufacturer | mpn | lcsc | jlc_class | pcba_type
J1 | UI_LINK / WR-MM 16 | OpenSaeco:Wurth_WR-MM_690367181672_2x08_P1.27mm_Vertical | owner_identified_supply_pending | Wurth Elektronik | 690367181672 | C19103863 | Extended | TBD
U1 | TCA9534PWR | Package_SO:TSSOP-16_4.4x5mm_P0.65mm | candidate | Texas Instruments | TCA9534PWR | C783615 | Extended | Economic and Standard
C1 | 100nF | Capacitor_SMD:C_0603_1608Metric | candidate | YAGEO | CC0603KRX7R9BB104 | C14663 | Basic | Economic and Standard
C2 | 1uF | Capacitor_SMD:C_0603_1608Metric | candidate | Samsung Electro-Mechanics | CL10A105KB8NNNC | C15849 | Basic | Economic and Standard
J2 | LCD_ADAPTER / JST PH 8 | Connector_JST:JST_PH_B8B-PH-K_1x08_P2.00mm_Vertical | candidate | JST | B8B-PH-K-S(LF)(SN) | C157974 | Extended | TBD
R1 | 4.7k | Resistor_SMD:R_0603_1608Metric | candidate | UNI-ROYAL | 0603WAF4701T5E | C23162 | Basic | Economic and Standard
R2 | 4.7k | Resistor_SMD:R_0603_1608Metric | candidate | UNI-ROYAL | 0603WAF4701T5E | C23162 | Basic | Economic and Standard
R3 | 10k | Resistor_SMD:R_0603_1608Metric | candidate | UNI-ROYAL | 0603WAF1002T5E | C25804 | Basic | Economic and Standard
R4 | 10k | Resistor_SMD:R_0603_1608Metric | candidate | UNI-ROYAL | 0603WAF1002T5E | C25804 | Basic | Economic and Standard
R5 | 10k | Resistor_SMD:R_0603_1608Metric | candidate | UNI-ROYAL | 0603WAF1002T5E | C25804 | Basic | Economic and Standard
R6 | 100k | Resistor_SMD:R_0603_1608Metric | candidate | UNI-ROYAL | 0603WAF1003T5E | C25803 | Basic | Economic and Standard
C3 | 10uF | Capacitor_SMD:C_0603_1608Metric | candidate | Samsung Electro-Mechanics | CL10A106MA8NRNC | C96446 | Basic | Economic and Standard
R11 | 10k / pull-up | Resistor_SMD:R_0603_1608Metric | candidate | UNI-ROYAL | 0603WAF1002T5E | C25804 | Basic | Economic and Standard
R21 | 1k / serie | Resistor_SMD:R_0603_1608Metric | candidate | UNI-ROYAL | 0603WAF1001T5E | C21190 | Basic | Economic and Standard
SW1 | KEY 1 / PB1 | OpenSaeco:SW_HRO_K2-1102SP-A4SC-04 | candidate | Korean Hroparts Elec | K2-1102SP-A4SC-04 | C83916 | Extended | Economic and Standard
C11 | 100nF / filtro | Capacitor_SMD:C_0603_1608Metric | candidate | YAGEO | CC0603KRX7R9BB104 | C14663 | Basic | Economic and Standard
R12 | 10k / pull-up | Resistor_SMD:R_0603_1608Metric | candidate | UNI-ROYAL | 0603WAF1002T5E | C25804 | Basic | Economic and Standard
R22 | 1k / serie | Resistor_SMD:R_0603_1608Metric | candidate | UNI-ROYAL | 0603WAF1001T5E | C21190 | Basic | Economic and Standard
SW2 | KEY 2 / PB2 | OpenSaeco:SW_HRO_K2-1102SP-A4SC-04 | candidate | Korean Hroparts Elec | K2-1102SP-A4SC-04 | C83916 | Extended | Economic and Standard
C12 | 100nF / filtro | Capacitor_SMD:C_0603_1608Metric | candidate | YAGEO | CC0603KRX7R9BB104 | C14663 | Basic | Economic and Standard
R13 | 10k / pull-up | Resistor_SMD:R_0603_1608Metric | candidate | UNI-ROYAL | 0603WAF1002T5E | C25804 | Basic | Economic and Standard
R23 | 1k / serie | Resistor_SMD:R_0603_1608Metric | candidate | UNI-ROYAL | 0603WAF1001T5E | C21190 | Basic | Economic and Standard
SW3 | KEY 3 / PB3 | OpenSaeco:SW_HRO_K2-1102SP-A4SC-04 | candidate | Korean Hroparts Elec | K2-1102SP-A4SC-04 | C83916 | Extended | Economic and Standard
C13 | 100nF / filtro | Capacitor_SMD:C_0603_1608Metric | candidate | YAGEO | CC0603KRX7R9BB104 | C14663 | Basic | Economic and Standard
R14 | 10k / pull-up | Resistor_SMD:R_0603_1608Metric | candidate | UNI-ROYAL | 0603WAF1002T5E | C25804 | Basic | Economic and Standard
R24 | 1k / serie | Resistor_SMD:R_0603_1608Metric | candidate | UNI-ROYAL | 0603WAF1001T5E | C21190 | Basic | Economic and Standard
SW4 | KEY 4 / PB8 | OpenSaeco:SW_HRO_K2-1102SP-A4SC-04 | candidate | Korean Hroparts Elec | K2-1102SP-A4SC-04 | C83916 | Extended | Economic and Standard
C14 | 100nF / filtro | Capacitor_SMD:C_0603_1608Metric | candidate | YAGEO | CC0603KRX7R9BB104 | C14663 | Basic | Economic and Standard
R15 | 10k / pull-up | Resistor_SMD:R_0603_1608Metric | candidate | UNI-ROYAL | 0603WAF1002T5E | C25804 | Basic | Economic and Standard
R25 | 1k / serie | Resistor_SMD:R_0603_1608Metric | candidate | UNI-ROYAL | 0603WAF1001T5E | C21190 | Basic | Economic and Standard
SW5 | KEY 5 / PB4/PB6 | OpenSaeco:SW_HRO_K2-1102SP-A4SC-04 | candidate | Korean Hroparts Elec | K2-1102SP-A4SC-04 | C83916 | Extended | Economic and Standard
C15 | 100nF / filtro | Capacitor_SMD:C_0603_1608Metric | candidate | YAGEO | CC0603KRX7R9BB104 | C14663 | Basic | Economic and Standard
R16 | 10k / pull-up | Resistor_SMD:R_0603_1608Metric | candidate | UNI-ROYAL | 0603WAF1002T5E | C25804 | Basic | Economic and Standard
R26 | 1k / serie | Resistor_SMD:R_0603_1608Metric | candidate | UNI-ROYAL | 0603WAF1001T5E | C21190 | Basic | Economic and Standard
SW6 | KEY 6 / PB5 | OpenSaeco:SW_HRO_K2-1102SP-A4SC-04 | candidate | Korean Hroparts Elec | K2-1102SP-A4SC-04 | C83916 | Extended | Economic and Standard
C16 | 100nF / filtro | Capacitor_SMD:C_0603_1608Metric | candidate | YAGEO | CC0603KRX7R9BB104 | C14663 | Basic | Economic and Standard
R17 | 10k / pull-up | Resistor_SMD:R_0603_1608Metric | candidate | UNI-ROYAL | 0603WAF1002T5E | C25804 | Basic | Economic and Standard
R27 | 1k / serie | Resistor_SMD:R_0603_1608Metric | candidate | UNI-ROYAL | 0603WAF1001T5E | C21190 | Basic | Economic and Standard
SW7 | KEY 7 / PB7 | OpenSaeco:SW_HRO_K2-1102SP-A4SC-04 | candidate | Korean Hroparts Elec | K2-1102SP-A4SC-04 | C83916 | Extended | Economic and Standard
C17 | 100nF / filtro | Capacitor_SMD:C_0603_1608Metric | candidate | YAGEO | CC0603KRX7R9BB104 | C14663 | Basic | Economic and Standard
R7 | 470 / LED | Resistor_SMD:R_0603_1608Metric | candidate | UNI-ROYAL | 0603WAF4700T5E | C23179 | Basic | Economic and Standard
D1 | KT-0603R / STBY | LED_SMD:LED_0603_1608Metric | candidate | Hubei KENTO Elec | KT-0603R | C2286 | Basic | Economic and Standard

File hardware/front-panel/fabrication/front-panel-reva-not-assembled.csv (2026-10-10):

Designator | Value | Manufacturer | MPN | Reason
J1 | UI_LINK / WR-MM 16 | Wurth Elektronik | 690367181672 | Sin stock en JLCPCB el 2026-10-10: comprar aparte y soldar a mano o aportar

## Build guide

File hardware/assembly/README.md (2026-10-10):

# Fabricación y montaje — objetivo JLCPCB

Preferencia del propietario, 2026-09-16: fabricar en JLCPCB o equivalente y diseñar
con componentes disponibles. Se adopta desde la selección de componentes; no se
esperará al final del layout para buscar referencias.

## Colocación de componentes (2026-10-10)

La [auditoría completa](placement-audit.md) registra las 265 referencias de las
dos placas: 250 incluidas en montaje y 15 excluidas. De las montadas, 242 tienen
correspondencia geométrica con los modelos públicos del visor de JLCPCB; L302
se ha contrastado con el plano de Bourns, y siete posiciones de la principal
requieren revisión. El [JSON](placement-audit.json) conserva
la evidencia y la corrección por referencia, huella y código LCSC.

Las convenciones de giro/cara inferior siguen Bouni, pero las correcciones se
contrastan por código LCSC: U301 y U303, por ejemplo, no usan el mismo giro a
pesar de compartir huella. No se cambia la geometría de la PCB para adaptar
el visor. Las discrepancias físicas quedan bloqueadas y documentadas.

Para repetir la auditoría después de cambios en PCB/BOM:

```text
python tools/fetch_jlc_placement_models.py <directorio-cache>
<python-de-KiCad> tools/audit_jlc_placements.py <directorio-cache>
python tools/export_front_panel_fab.py
python tools/export_controller_fab.py --allow-unverified
python -m unittest discover -s tests -p test_jlc_placements.py
```

La caché contiene las respuestas originales de terceros y no se incorpora al
repositorio. Para refrescar una respuesta, usar un directorio de caché nuevo.
El exportador verifica SHA-256 de la PCB (con saltos LF normalizados), identidad
de la BOM y posición original; no reutiliza correcciones de una revisión anterior
sin repetir la auditoría. El informe distingue ausencia de modelo, discrepancia
geométrica y correspondencia. Esta última no equivale a aprobar la fabricación.

La principal solo permite generar un archivo `-cpl-jlcpcb-review.csv` mientras
haya pendientes; no se debe confirmar el montaje con ese archivo. El frontal
conserva su nombre de CPL habitual. Ambos requieren comprobar la vista previa
del pedido, especialmente pin 1, polaridad y boca de conectores.

## Catálogo trazable

[parts-catalog.json](parts-catalog.json) registra MPN, fabricante, código JLC/LCSC,
huella candidata, categoría, modalidad de montaje, URL y fecha de consulta.
Existencias de la tabla consultadas el **2026-10-05** en la API pública de
búsqueda de JLCPCB con `tools/refresh_jlc_stock.py` (cada pieza lleva su fecha
en el catálogo), sin iniciar sesión ni hacer compras.
Son una instantánea, no una reserva.
`stock_observed` y `available_order_qty_observed` son campos distintos de la web;
un valor `null` significa no observado, no cero ni disponibilidad garantizada.

| Función | Referencia | Código | Stock observado | Cantidad disponible para pedido observada | Montaje |
|---|---|---|---:|---:|---|
| Control principal | STM32G431RBT6 | [C431633](https://jlcpcb.com/partdetail/C431633) | 578 | 465 | Economic / Standard |
| Interfaz y comunicaciones, antena externa U.FL | ESP32-S3-WROOM-1U-N8R8 | [C2980300](https://jlcpcb.com/partdetail/3401552-ESP32_S3_WROOM_1UN8R8/C2980300) | 1.441 | 1.303 | Standard Only |
| Botones frontal | TCA9534PWR | [C783615](https://jlcpcb.com/partdetail/C783615) | 15.097 | 14.950 | Economic / Standard |
| Regulador 3,3 V / 2 A | AP63203WU-7 | [C780769](https://jlcpcb.com/partdetail/C780769) | 17.624 | 13.514 | Economic / Standard |
| Corte y límite de alimentación del frontal y de JP22 (×2) | TPS2553DBVR | [C55266](https://jlcpcb.com/partdetail/C55266) | 57.596 | 56.686 | Economic / Standard |
| Puente H motor del grupo | DRV8876PWPR | [C575551](https://www.lcsc.com/product-detail/C575551.html) | 29.841 | 29.572 | Extended; categoría JLC por verificar |
| Driver de puerta de válvula, candidato | UCC27517DBVR | [C99395](https://www.lcsc.com/product-detail/C99395.html) | 49.012 | 46.195 | Extended; categoría JLC por verificar |
| MOSFET de válvula, candidato | UMW SI2308A, 60 V/3 A | [C347491](https://www.lcsc.com/product-detail/C347491.html) | 517.717 | 514.495 | Extended; categoría JLC por verificar |
| MOSFET del relé y de los LED de los optos | onsemi BSS138LT1G, 50 V/200 mA, 10 Ω a VGS 2,75 V | [C82045](https://jlcpcb.com/partdetail/C82045) | 549.996 | 547.327 | Extended; categoría PCBA por verificar |
| Conector JP3 | HR A2506WV-05P, 5 vías/2,50 mm, vertical | [C382535](https://jlcpcb.com/partdetail/C382535) | 3 | 0 | Extended; categoría JLC por verificar |
| Supervisor/watchdog | TI TPS3828-33DBVR | [C20032](https://www.lcsc.com/product-detail/C20032.html) | 65.894 | 65.817 | Extended; categoría JLC por verificar |
| Buffer Schmitt del reset de los interlocks | TI SN74LVC1G17DBVR | [C7836](https://jlcpcb.com/partdetail/C7836) | 57.737 | 55.232 | Extended; categoría PCBA por verificar |
| Puerta del WDI del supervisor | TI SN74LVC1G132DBVR, NAND con entradas Schmitt | [C403723](https://jlcpcb.com/partdetail/C403723) | 30.058 | 22.508 | Extended; categoría PCBA por verificar |
| Corriente del molinillo | TI TMCS1133B4AQDVGR, Hall aislado reforzado, SOIC-10 ancho | [C36873216](https://jlcpcb.com/partdetail/C36873216) | 163 | — | Extended; categoría PCBA por verificar; alternativa TMCS1123B4AQDVGR (C30955591) |
| Interlock doble | TI SN74LVC2G08DCTR | [C352973](https://www.lcsc.com/product-detail/C352973.html) | 34.113 | 34.075 | Extended; categoría JLC por verificar |
| Bulk motor del grupo | Lelon VZH101M1VTR-0607, 100 µF/35 V | [C176683](https://jlcpcb.com/partdetail/Lelon-VZH101M1VTR0607/C176683) | 31.003 | 22.085 | Economic / Standard |
| Bomba de carga DRV8876 | 22 nF/50 V X7R 0603 | [C77571](https://www.lcsc.com/product-detail/C77571.html) | 309.390 | 300.942 | Economic / Standard |
| USB-C de servicio | HRO TYPE-C-31-D-06, vertical | [C2689964](https://jlcpcb.com/partdetail/C2689964) | 2.315 | 2.221 | Extended; categoría JLC por verificar |
| Protección ESD USB | USBLC6-2SC6 | [C7519](https://jlcpcb.com/partdetail/C7519) | 44.845 | 40.942 | Economic / Standard |
| PTC alimentación USB opcional | Littelfuse 1206L050YR | [C163512](https://www.lcsc.com/product-detail/C163512.html) | 20.659 | 20.589 | Extended; categoría JLC por verificar |
| Inductor buck | SRN6028C-3R9M | [C19947652](https://www.lcsc.com/product-detail/C19947652.html) | 206 | 201 | Economic / Standard |
| Salida buck, 2 unidades | 22 µF/10 V X5R 0805 | [C380338](https://jlcpcb.com/partdetail/CCTC-TCC0805X5R226M100FT/C380338) | 278.038 | 270.135 | Economic / Standard |
| Entradas 12 V y 24 V, 2 unidades | JST B2B-XH-A(LF)(SN), vertical | [C158012](https://jlcpcb.com/partdetail/C158012) | 299.927 | 284.120 | Extended; categoría JLC por verificar |
| JP13 | HR A2506WV-02P, 2 vías/2,50 mm, vertical | [C382532](https://jlcpcb.com/partdetail/C382532) | 700 | 698 | Extended; categoría JLC por verificar |
| JP14 | JST B2B-XH-A(LF)(SN), vertical, candidato no confirmado | [C158012](https://jlcpcb.com/partdetail/C158012) | 299.927 | 284.120 | Extended; categoría JLC por verificar |
| JP5 | HR A2506WV-03P, 3 vías/2,50 mm, vertical | [C382533](https://jlcpcb.com/partdetail/C382533) | 0 | 0 | Extended; sin stock |
| JP16 | JST B8B-XH-A(LF)(SN), vertical, candidato no confirmado | [C157972](https://jlcpcb.com/partdetail/C157972) | 10.707 | 10.076 | Extended; categoría JLC por verificar |
| JP22 | JST B3B-PH-K-S(LF)(SN), vertical, candidato no confirmado | [C131339](https://jlcpcb.com/partdetail/C131339) | 218.431 | 203.251 | Extended; categoría JLC por verificar |
| JP24 | LEOCO 5001P020013, 2 vías/5,00 mm, pin cuadrado, vertical | Sin código JLCPCB | — | — | Soldadura manual o pieza aportada |
| JP8 | LEOCO 3941P03*000, 3 vías/3,96 mm, vertical | Sin código JLCPCB | — | — | Soldadura manual o pieza aportada |
| JP17 | TE 1971845-3, RAST 5, 3 lengüetas 6,3 × 0,8 mm, 16 A, vertical | [C5169636](https://jlcpcb.com/partdetail/C5169636) | 233 | 233 | Extended; categoría JLC por verificar |
| Fuente aislada integrada | Mean Well IRM-30-24, 24 V/1,3 A | [C6280124](https://jlcpcb.com/partdetail/MW_MEAN_WELL_Enterprises-IRM_3024/C6280124) | 12.970 | 12.658 | Economic / Standard; ola |
| Relé general de cargas | Omron G5RL-1A-E-HR DC24, 16 A (sustituye al -E-TV8, sin stock, el 2026-10-08) | [C397236](https://jlcpcb.com/partdetail/C397236) | 639 | 629 | Economic / Standard; ola |
| Varistor de entrada RV701 | TDK B72214S0271K101 (S14K275), 275 VAC, 4,5 kA, 71 J | [C7502584](https://jlcpcb.com/partdetail/C7502584) | 322 | 239 | Economic / Standard; ola |
| Buck 24 V → 12 V | Diodes AP63301WU-7, 3 A, PWM fijo (sustituye al AP63200WU-7, sin stock, el 2026-10-08) | [C2158003](https://jlcpcb.com/partdetail/C2158003) | 5.107 | 4.906 | Extended; categoría JLC por verificar |
| Inductor buck 12 V | Bourns SRP7028A-100M, 10 µH/3,5 A | [C2687402](https://www.lcsc.com/product-detail/C2687402.html) | 4.948 | 4.894 | Extended; categoría JLC por verificar |
| Entrada buck 24 V | Samsung CL31B106KBHNNNE, 10 µF/50 V X7R | [C89632](https://jlcpcb.com/partdetail/90812-CL31B106KBHNNNE/C89632) | 124.899 | 55.244 | Economic / Standard; Extended |
| Salida buck 12 V, 2 unidades | CCTC TCC1210X7R226K250MT, 22 µF/25 V X7R | [C49118556](https://jlcpcb.com/partdetail/CCTC-TCC1210X7R226K250MT/C49118556) | 84.392 | 76.945 | Economic / Standard; Extended |
| Triac de potencia, candidato | ST BTA24-800BWRG, 25 A/800 V | [C15293](https://jlcpcb.com/partdetail/Stmicroelectronics-BTA24800BWRG/C15293) | 1.077 | 1.032 | Extended; categoría JLC por verificar |
| Optotriac calentador, bomba y molinillo | Lite-On MOC3083, cruce por cero/800 V | [C10797](https://jlcpcb.com/partdetail/liteon-MOC3083/C10797) | 18.898 | 18.838 | Extended; categoría JLC por verificar |
| SWD/UART, 2 unidades | 1×6 2,54 mm vertical | [C52016393](https://jlcpcb.com/partdetail/C52016393) | 34.279 | 34.114 | Economic / Standard |
| Enlace principal–frontal, 2 unidades | Würth WR-MM 690367181672, 16 contactos 1,27 mm al tresbolillo (identificado por el propietario) | [C19103863](https://jlcpcb.com/partdetail/C19103863) | 0 | 0 | Sin stock el 2026-10-01; tipo PCBA por verificar |

Los integrados y magnéticos figuran como Extended; los pasivos de mayor volumen
se han elegido Basic cuando existe una referencia adecuada. El código
genérico de montaje `C9900171795` no identifica la variante N8R8 del módulo:
no sustituye a `C2980300`. El VOT8125AG de disparo aleatorio que se barajó para
bomba y molinillo no tenía existencias en DIP; se usa el MOC3083 en las tres
cargas.

El DRV8876 figura en LCSC con stock, pero aún no se ha verificado su categoría ni
su disponibilidad dentro del selector de montaje de JLCPCB. Ya forma parte del
esquema y de la BOM candidata junto con el bulk, la bomba de carga y la red de
medida; sigue sin estar liberado para compra hasta validar el motor y la térmica.

La principal se orienta a **Standard PCBA** por el módulo ESP32 seleccionado y
requerirá montaje mixto/reflow más ola para módulo AC/DC, relé y conectores. El
frontal podría cotizarse aparte en Economic, sujeto a los conectores/pulsadores
que se elijan. No hay presupuesto de montaje calculado; las categorías no bastan
para deducir el precio total de un pedido.

## Decisión STM32

Para el núcleo de Rev A se selecciona como referencia de trabajo STM32G431RBT6,
LQFP64, 128 KB Flash / 32 KB RAM. Los menús, red y pantalla viven en el ESP32;
el control queda en el STM32. El margen real de firmware debe comprobarse al
añadir BSP, protocolo y adquisición: no se ha demostrado aún su capacidad final.

Se compararon también, sin seleccionarlos:
- [STM32G474RET6 / C521608](https://jlcpcb.com/partdetail/C521608): la página
  mostraba 52 en stock y acción «Pre-order»; 13,3943 USD estimados por unidad.
- [STM32G474VET6 / C431632](https://jlcpcb.com/partdetail/C431632): cero en stock,
  LQFP100. No se adopta como alternativa disponible.

G431RBT6 mostraba 4,9501 USD para una unidad; precios de la consulta, sin impuestos,
montaje ni transporte. No son presupuesto. No se aprueba ninguna sustitución
G431/G474 automáticamente: hay que revisar pinout, periféricos, memoria y firmware.

## BOM de cada placa

- [Principal](../controller/bom-draft.csv): 223 posiciones. 213 tienen MPN y
  código LCSC, de ellas R415 y R416 sin montar (DNP, issue #7); C705, R727,
  C706 y R728 son snubbers RC sin montar ni pieza elegida (PU-03 y GR-05), y
  C708 un condensador de supresión del molinillo en las mismas condiciones
  (EM-01); C707 es el X2 de entrada, Murata GA355XR7GB563KW06L (C161105); J115 y J117 (LEOCO) tienen MPN pero no código, porque JLCPCB no
  las vende; RV701 es un TDK S14K275 desde el 2026-10-08; J111 y J121 son
  puentes de cobre. F701 y F702 son Littelfuse 215 de 1500 A desde el 2026-10-06:
  F701 de 12 A, axial y soldado como el F1 original, y F702 de 2 A, como el
  F2 original, en dos pinzas Littelfuse 01110501Z (C151075) que no son
  posiciones del esquema. J107 y J108 (JP14 y JP16) son HR A2506WV-02P y
  -08P (C382532, C476906; la -08P sin stock) y J109 (JP22) una JST B3B-ZR
  (C158001), identificadas por el propietario el 2026-10-10.
- [Frontal](../front-panel/bom-draft.csv): 42 de 42 posiciones con MPN y código.
  Añadidos el 2026-09-18: pulsador HRO K2-1102SP-A4SC-04 6 × 6 × 4,3 mm (C83916,
  Extended; no hay 6 × 6 SMD Basic), JST B8B-PH-K-S(LF)(SN) vertical (C157974, Extended, sustituye el 2026-09-22 al lateral C157915),
  LED KT-0603R (C2286, Basic) y 470 Ω (C23179, Basic). Paquete JLCPCB candidato en
  [front-panel/fabrication](../front-panel/fabrication/).

Los mismos campos están embebidos en los símbolos de los esquemas; el generador
reutiliza el catálogo y comprueba huellas.

El propietario identificó el 2026-09-29 las cabeceras de JP3, JP5, JP13, JP8 y
JP24. Las tres de señal son HR (Joint Tech) A2506WV y están en JLCPCB, pero con
poco stock: la de cinco vías tenía 3 unidades y la de tres, ninguna (igual el
2026-10-01, con ambas ya reservadas por encima del stock)
(`C9900130733`, la A2506WV-03P blanca de JLCPCB Assembly, tampoco tenía). Habrá
que reservarlas o comprarlas en LCSC antes del pedido. JP8 y JP24 son LEOCO
3941P03*000 y 5001P020013; JLCPCB no tiene LEOCO ni ninguna de las dos series,
así que su línea de la BOM va sin código LCSC y se sueldan a mano o se aportan
a JLCPCB. Para la 3941, el `*` es la opción de pin (V cuadrado, R redondo); la
huella usa el taladro de 1,80 mm del pin cuadrado, que admite los dos. JP8 y
JP24 transportan tensión peligrosa: fijar el conector no libera la arquitectura
eléctrica ni el layout de esos circuitos.

Capacitores de 100 nF y 10 nF: X7R. De 1 µF, 4,7 µF y 10 µF: X5R seleccionados
por suministro. Cerrar temperatura y capacitancia efectiva bajo polarización
antes de liberarlos; no aplicar una sustitución por valor nominal solamente.
Los MPN mecánicos no se elegirán por stock antes de conocer altura, paso y encaje.

## Objetivos de layout

Son decisiones iniciales de diseño, no reglas mínimas publicadas por el fabricante:
- Principal: cuatro capas desde el 2026-09-23 (JLC04161H-7628: planos de GND y
  3,3 V internos solo en el lado SELV), con dominios, retornos y barrera de
  aislamiento controlados. Ver el [perfil de fabricación](../controller/manufacturing.md).
  Frontal: dos capas.
- Componentes SMD preferiblemente en una cara; pasivos 0603 (1608 métrico).
- Encapsulados con patas accesibles: LQFP64 y TSSOP; módulo de RF con conector U.FL
  para antena externa.
- En señales lógicas, comenzar con pistas/espacios de 0,20 mm y vías 0,60/0,30 mm;
  revisar con stack-up y cotización. Estas cifras **no** dimensionan aislamiento
  de red, pistas de potencia, térmica ni impedancia USB.
- Comprobar huellas contra planos del fabricante y pin 1, no contra la foto de catálogo.
- Conectores de potencia, elementos térmicos y THT pueden necesitar montaje mixto;
  documentar qué monta fábrica y qué se monta después.

## Paquete de fabricación futuro

Cuando haya PCB revisada: Gerbers y taladros, BOM de montaje, CPL de posiciones,
planos de ensamblaje, exclusiones DNP, revisión de fabricación y registro de ERC/DRC.
La [guía oficial de BOM](https://jlcpcb.com/help/article/bill-of-materials-for-pcb-assembly)
identifica Comment, Designator y Footprint. Añadiremos el código de componente
para evitar coincidencias ambiguas. Las referencias de BOM y CPL deben coincidir;
ver [guía de preparación](https://jlcpcb.com/help/article/advice-for-bom-and-cpl-files-preparation).

La principal tiene un paquete candidato en
[controller/fabrication](../controller/fabrication/), generado por
`tools/export_controller_fab.py`, con la lista de lo que JLCPCB no monta; no se
pide hasta cerrar la revisión (ver [manufacturing.md](../controller/manufacturing.md#paquete-jlcpcb-candidato)).
El frontal ya tiene Gerbers, BOM y CPL generados por
`tools/export_front_panel_fab.py`, pendientes de revisión antes del pedido. Antes de cotizar, refrescar stock y cantidades con merma,
revisar orientaciones en la vista de montaje y cerrar las piezas todavía pendientes.

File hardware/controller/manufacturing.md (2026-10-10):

# Perfil de fabricación de la controladora

Estado: perfil aplicado a la PCB ruteada y [paquete JLCPCB candidato](#paquete-jlcpcb-candidato)
generado; aún no liberado para fabricar.

La principal es FR-4 de cuatro capas y 1,6 mm, el mismo espesor medido en la
placa original. Se pasó de dos a cuatro capas el 2026-09-23: con dos, B.Cu era a
la vez plano de GND y capa de saltos, y cada salto troceaba el plano; los
últimos 29 enlaces de señal no cabían sin decenas de vías más, y el 3,3 V
viajaba como una espina de 506 mm con una docena de saltos. El apilado es el
estándar de JLCPCB, JLC04161H-7628, según su
[página de impedancias](https://jlcpcb.com/impedance) (consultada el
2026-09-23):

| Capa | Cobre | Uso |
|---|---|---|
| F.Cu | 1 oz (0,035 mm) | componentes, señales y potencia local |
| preimpregnado 7628 | 0,2104 mm, εr 4,4 | |
| In1.Cu | 0,5 oz (0,0152 mm) | plano GND_UI continuo en el lado SELV, referencia de F.Cu |
| núcleo | 1,065 mm, εr 4,6 | |
| In2.Cu | 0,5 oz (0,0152 mm) | plano 3V3_CORE en el lado SELV |
| preimpregnado 7628 | 0,2104 mm, εr 4,4 | |
| B.Cu | 1 oz (0,035 mm) | señales y saltos, sin plano |

`tools/configure_controller_stackup.py` escribe este apilado en la placa y
`layout_controller_pcb.py` fija las cuatro capas de cobre; las áreas de regla
(barrera, paso de red y ranuras de optos) cubren las cuatro, y la del pie del
disipador todas menos B.Cu.

- Ninguna capa interna lleva cobre en el dominio de red: los dos planos acaban
  en el borde SELV de la banda de barrera y el DRC los mantiene a 8 mm de todo
  cobre `Mains`. Las fases siguen duplicadas en F.Cu y B.Cu.
- In2.Cu solo lleva dos pistas de señal: las subidas de `BREW_SLEEP_INTERLOCK`
  y `WATCHDOG_KICK_RAW` junto al supervisor (33 mm en total), para que el bus
  de sensores cruce esa columna por B.Cu. Son líneas lentas y el plano de
  3,3 V sigue siendo una sola pieza.
- El plano de 3,3 V sustituye la antigua espina: cada condensador de desacoplo
  y cada grupo de pads baja a él con su propia vía.

El cobre exterior es de 1 oz. Las pistas de red que llevan la corriente de
carga se duplican en las dos caras con vías de cosido en lugar de pasar a 2 oz,
que sale más caro en JLCPCB. La pareja USB va en F.Cu sobre el plano de masa de
In1.Cu, a 0,21 mm. Con la calculadora de JLCPCB para este apilado
(2026-09-23), 90 Ω diferenciales piden 0,29 mm de ancho y 0,20 mm de
separación; es la regla de la clase USB y el ancho del tramo acoplado. No se
pide impedancia controlada: el USB es Full Speed y el par es corto (ver
[service-usb.md](../../docs/service-usb.md)).

Rellenos exteriores (2026-09-23): en el lado SELV, F.Cu y B.Cu llevan masa
`GND_UI`, cosida al plano de In1.Cu con vías de 0,6 mm en una rejilla de 5 mm
donde caben. Ayudan a disipar bajo los reguladores y el puente H, apantallan y
equilibran el cobre. Los pads SMD se unen macizos y los de agujero pasante con
alivios. Separación de 0,5 mm alrededor, para no bajar la impedancia del par
USB. En el lado de red no hay relleno: no queda cobre flotante en el dominio
primario, y las reglas de 8 mm mantienen la masa lejos de todo cobre `Mains`.

## Reglas de KiCad

`tools/configure_controller_rules.py` mantiene las clases de red:

| Clase | Ancho | Separación | Vía / taladro | Redes |
|---|---:|---:|---:|---|
| Mains | 2,50 mm | 1,20 mm* | 1,60 / 0,80 mm | L, N, fases de carga y bus del molinillo |
| Default | 0,20 mm | 0,20 mm | 0,60 / 0,30 mm | lógica y analógicas |
| USB | 0,20 mm (par 0,29 / 0,20) | 0,20 mm | 0,60 / 0,30 mm | D+/D− de puerto, protección y dispositivo |
| Power | 0,50 mm | 0,20 mm | 0,80 / 0,40 mm | 3,3 V, 12 V y VBUS |
| Switching | 0,60 mm | 0,25 mm | 0,80 / 0,40 mm | nodos del buck y charge pump |
| Actuator | 1,00 mm | 0,25 mm | 1,00 / 0,50 mm | 24 V, motor y electroválvula |

\* Entre pads de red la limita el paso de 3,96 mm de la cabecera LEOCO 3941 de JP8. El mismo
script escribe `controller-core-reva.kicad_dru`, que exige 2,5 mm entre pistas de
redes `Mains` distintas y 8 mm de separación y creepage entre `Mains` y SELV.

Son valores deliberadamente más conservadores que los mínimos publicados por
JLCPCB para cobre de 1 oz. La tabla de capacidades consultada el 2026-09-19
admite dos capas, placas mayores que 141,6 × 135,2 mm y pistas/espacios mucho
menores que 0,20 mm. La fuente es la
[tabla oficial de capacidades de JLCPCB](https://jlcpcb.com/capabilities/Capab).

Como referencia comercial publicada por JLCPCB el 2026-09-19, la producción
por superficie se anuncia desde 56 USD/m² para dos capas y 91 USD/m² para cuatro
capas, con plazos anunciados de 24 horas y cuatro días respectivamente. La
cotización real depende de cantidad, acabado, montaje, promociones y envío. El
sobrecoste se acepta a cambio de planos continuos y de un ruteo cerrado sin
trocear la masa.

JP8 y JP24 son las LEOCO 3941P03*000 y 5001P020013; JLCPCB no las monta, así
que van a mano o como piezas aportadas. JP19 y JP17 son los TE 1971845-4 y 1971845-3 y
JP1/JP9 son TE 63824-1. La zona de red y bus rectificado no comparte relleno,
vías ni retornos con el plano GND de SELV. La barrera inicial de 8 mm ya se
comprueba en el DRC y se revisará antes de fabricar.

## Paquete JLCPCB candidato

`tools/export_controller_fab.py` lo escribe en [fabrication/](fabrication/) desde
la PCB y la [BOM](bom-draft.csv). No es una liberación: el script lista al final
lo que sigue abierto y saca de la BOM de JLCPCB lo que no tenía stock
en la última consulta (`tools/refresh_jlc_stock.py`): hoy J104 (Würth WR-MM),
J106 (HR A2506WV-03P) y J108 (HR A2506WV-08P), THT, que se compran aparte y se
sueldan a mano. Los de J106 y J108 pueden salir de la placa original, que lleva
las mismas cabeceras.

| Archivo | Contenido |
|---|---|
| [controller-core-reva-gerbers.zip](fabrication/controller-core-reva-gerbers.zip) | Gerber de 4 capas (extensiones Protel, máscara restada de la serigrafía), trabajo `.gbrjob` con el apilado, Excellon en mm con PTH y NPTH separados, y mapas de taladros |
| [controller-core-reva-bom-jlcpcb.csv](fabrication/controller-core-reva-bom-jlcpcb.csv) | 69 líneas / 209 posiciones: Comment, Designator, Footprint, LCSC Part # |
| [controller-core-reva-cpl-jlcpcb-review.csv](fabrication/controller-core-reva-cpl-jlcpcb-review.csv) | Solo revisión: correcciones contrastadas por código LCSC, siete posiciones pendientes; C707 en Bottom |
| [controller-core-reva-not-assembled.csv](fabrication/controller-core-reva-not-assembled.csv) | Lo que JLCPCB no monta y por qué |

Los PTH y NPTH van en ficheros separados: en uno solo, únicamente los comentarios
del Excellon dicen qué agujero se metaliza. JLCPCB no monta:

- J111 (DNP) y J121: puentes de soldadura, cobre sin pieza.
- R415 y R416 (DNP): polarización de JP22, a la espera de WL-01 (issue #7).
- C705, R727, C706 y R728 (DNP, cara inferior): snubbers RC de Q704 y Q708, a
  la espera de PU-03 y GR-05.
- C708 (DNP, cara inferior): supresión del molinillo, a la espera de EM-01.

C707, el X2 de entrada, es la única pieza montada en la cara inferior. Con él en
el CPL el pedido es de montaje a doble cara; si sale más barato, se quita del
CPL y se suelda a mano (2220).
- J115 y J117 (LEOCO de JP8 y JP24): sin código JLCPCB, se sueldan a mano o se aportan.

Opciones del pedido: 4 capas, 1,6 mm, apilado JLC04161H-7628 (1 oz exterior,
0,5 oz interior), sin impedancia controlada. Montaje en la cara superior; hay
piezas THT y el ESP32 es «Standard Only», así que va en montaje Standard.
`check_controller_core.py` falla en CI si la BOM o el CPL dejan de coincidir con
la BOM de diseño; no comprueba los Gerbers, que hay que regenerar tras cada
cambio de la PCB.

En la vista previa de JLCPCB, antes de confirmar: pin 1 de U101, U201 y de cada
integrado; polaridad de diodos, puentes rectificadores y electrolíticos; y la
boca de cada conector hacia el borde. Las rotaciones y centros del CPL incorporan
la [auditoría por componente](../assembly/placement-audit.md), contrastada con
los modelos públicos enlazados desde JLCPCB. La exportación normal se detiene
si la PCB o la BOM cambiaron desde la auditoría o si hay colocaciones sin resolver.

**El paquete principal no está liberado para montar:** K701 tiene una huella con
20 mm entre columnas extremas donde el fabricante requiere 25 mm; F702 mezcla
una huella de clips con el código de un fusible suelto. También requieren revisión
J118, F701/F703 y los modelos ausentes de C314/F306. El informe explica cada
caso. Para revisar las otras correcciones en el visor se genera expresamente
`python tools/export_controller_fab.py --allow-unverified`; ese CPL lleva el
sufijo `-review` y conserva las posiciones originales de los siete pendientes.
Se ha retirado el CPL anterior sin correcciones para evitar confundirlo con este.

La huella de KiCad del ESP32-S3-WROOM-1U lleva 12 vías de 0,2 mm en el pad de
masa central, sin tapar. Confirmar con JLCPCB el taladro de 0,2 mm y si la
soldadura se escapa por ellas.

## Antes de pedir

- Pedir JLC04161H-7628 (1,6 mm, 1 oz exterior y 0,5 oz interior). La
  geometría USB ya está calculada con ese apilado.
- Validar con JLCPCB material, acabado, ranuras y reglas reales de separación de
  la zona de red, también entre capas internas y externas.
- Revisar capacidad de corriente y temperatura de las pistas de 24 V con cobre,
  longitud, vías y corriente medidas, incluida la corriente de bloqueo del motor.
- Revisar las dos ranuras de In2.Cu bajo el supervisor (los rellenos
  exteriores ya están decididos).
- Revisar en 3D alturas (≤ 35 mm, cota comprobada con el disipador original),
  orientación de conectores y acceso al USB.
- Ejecutar ERC, DRC, paridad esquema/PCB y la prueba mecánica 1:1 con
  `preview/controller-top-1to1.pdf` impreso al 100 %.
- Refrescar stock (`tools/refresh_jlc_stock.py`), regenerar el paquete y
  revisarlo en el visor de Gerbers de JLCPCB.

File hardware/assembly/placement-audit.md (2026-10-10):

# Auditoría de colocación JLCPCB

Fecha: 2026-10-10. **Candidatos para revisión, no liberados para fabricar.**

Se comprueba cada referencia de ambas BOM, incluidas las excluidas del montaje. Para cada código LCSC se contrasta la huella pública enlazada por JLCPCB con los pads numerados de la PCB. Los alias eléctricos están documentados; no se aplica una corrección por el mero nombre del encapsulado.

Fuente: [JLCEDA/EasyEDA Official Library](https://easyeda.com), [JLCEDA](https://lceda.cn/), a través del visor de las fichas de JLCPCB. Los SVG originales quedan en caché local; el JSON registra URL, UUID y SHA-256. No se redistribuyen las bibliotecas originales.

La comparación comprueba orientación y centro, no tolerancias de fabricación, soldabilidad ni aprobación de la previsualización de un pedido concreto. El umbral de 0,30 mm es un filtro para diferencias entre land patterns, no una tolerancia admisible de colocación de la máquina.

Se usa el enfoque de [Bouni](https://github.com/Bouni/kicad-jlcpcb-tools/blob/b2ff3a08173e04d77ba35019bc1670a9c3f1317d/fabrication.py) para ángulos/cara inferior, con reglas exactas por pieza verificadas contra pads. La tabla genérica da resultados distintos para varios SOT/TSOT. El centro se obtiene alineando los extremos de los pads numerados: incluir un tetón NPTH como hace el bounding box genérico desplaza J116/J118.

## Pendientes de las posiciones montadas

- **controller F306 / C2838912:** NO MODEL: public API has no PCB footprint. Nonpolarized 1206 fuse; retained original CPL, pending vendor preview.
- **controller J118 / C5169636:** REVIEW: paired tails differ by 2.5 mm with contact order preserved. Check TE drawing, locating post and harness pin 1; do not rotate to conceal a contact reversal.
- **controller F701 / C142789:** REVIEW: model lead pitch 25.50 mm versus PCB 27.50 mm; axial leads need forming. Confirm the assembly operation with JLCPCB.
- **controller F702 / C142716:** BLOCKED: BOM orders a leadless 0215002.MXP fuse, but PCB footprint is a pair of Littelfuse 111 clips. Clips are not separate BOM items. Resolve assembly BOM/mechanics.
- **controller C314 / C49326334:** NO MODEL: public API has no PCB footprint. Nonpolarized 0603 capacitor; retained original CPL, pending vendor preview.
- **controller K701 / C397236:** BLOCKED: K701 holes span 20 mm; Omron G5RL-1A-E-HR requires 25 mm (20+5). Fix footprint/routing, not CPL. Source: https://omronfs.omron.com/en_US/ecb/products/pdf/en-g5rl.pdf page 5.
- **controller F703 / C178840:** REVIEW: model is horizontal at 28 mm pitch, PCB is vertical at 5.08 mm. Requires lead forming/manual assembly; rotating a horizontal model cannot validate it.

## Resultado por componente

ΔX/ΔY son desplazamientos en ejes del CPL (X derecha, Y arriba), después de considerar el giro y la cara de la placa. Δθ es la corrección local; la columna final incluye también la convención de cara inferior. Los pendientes conservan los valores originales en el archivo de revisión.

| Placa | Ref | LCSC | Montaje | Estado | Δθ | ΔX mm | ΔY mm | Giro final | Error máximo pads mm |
|---|---|---|---|---|---:|---:|---:|---:|---:|
| controller | U101 | [C431633](https://jlcpcb.com/partdetail/C431633) | sí | geometry_match | 270 | 0.0000 | 0.0000 | 270.0 | 0.02483 |
| controller | U201 | [C2980300](https://jlcpcb.com/partdetail/C2980300) | sí | geometry_match | 0 | 0.0000 | -0.6200 | 0.0 | 0.0154 |
| controller | J101 | [C158012](https://jlcpcb.com/partdetail/C158012) | sí | geometry_match | 180 | 1.2500 | 0.0000 | 180.0 | 0.00032 |
| controller | J102 | [C52016393](https://jlcpcb.com/partdetail/C52016393) | sí | geometry_match | 270 | 6.3500 | 0.0000 | 0.0 | 0.0 |
| controller | J103 | [C52016393](https://jlcpcb.com/partdetail/C52016393) | sí | geometry_match | 270 | 6.3500 | 0.0000 | 0.0 | 0.0 |
| controller | J104 | [C19103863](https://jlcpcb.com/partdetail/C19103863) | excluido | no_model | — | 0.0000 | 0.0000 | 180.0 | — |
| controller | R101 | [C25804](https://jlcpcb.com/partdetail/C25804) | sí | geometry_match | 0 | 0.0000 | 0.0000 | 0.0 | 0.07062 |
| controller | C101 | [C14663](https://jlcpcb.com/partdetail/C14663) | sí | geometry_match | 0 | 0.0000 | 0.0000 | 0.0 | 0.07396 |
| controller | R102 | [C25804](https://jlcpcb.com/partdetail/C25804) | sí | geometry_match | 0 | 0.0000 | 0.0000 | 90.0 | 0.07062 |
| controller | R201 | [C25804](https://jlcpcb.com/partdetail/C25804) | sí | geometry_match | 0 | 0.0000 | 0.0000 | 90.0 | 0.07062 |
| controller | C201 | [C15849](https://jlcpcb.com/partdetail/C15849) | sí | geometry_match | 0 | 0.0000 | 0.0000 | 90.0 | 0.07396 |
| controller | R202 | [C25804](https://jlcpcb.com/partdetail/C25804) | sí | geometry_match | 0 | 0.0000 | 0.0000 | 270.0 | 0.07062 |
| controller | R211 | [C23140](https://jlcpcb.com/partdetail/C23140) | sí | geometry_match | 0 | 0.0000 | 0.0000 | 0.0 | 0.07062 |
| controller | R212 | [C23140](https://jlcpcb.com/partdetail/C23140) | sí | geometry_match | 0 | 0.0000 | 0.0000 | 0.0 | 0.07062 |
| controller | R213 | [C23140](https://jlcpcb.com/partdetail/C23140) | sí | geometry_match | 0 | 0.0000 | 0.0000 | 90.0 | 0.07062 |
| controller | R214 | [C23140](https://jlcpcb.com/partdetail/C23140) | sí | geometry_match | 0 | 0.0000 | 0.0000 | 90.0 | 0.07062 |
| controller | R215 | [C23140](https://jlcpcb.com/partdetail/C23140) | sí | geometry_match | 0 | 0.0000 | 0.0000 | 90.0 | 0.07062 |
| controller | R216 | [C23140](https://jlcpcb.com/partdetail/C23140) | sí | geometry_match | 0 | 0.0000 | 0.0000 | 90.0 | 0.07062 |
| controller | R217 | [C23140](https://jlcpcb.com/partdetail/C23140) | sí | geometry_match | 0 | 0.0000 | 0.0000 | 90.0 | 0.07062 |
| controller | R218 | [C23140](https://jlcpcb.com/partdetail/C23140) | sí | geometry_match | 0 | 0.0000 | 0.0000 | 90.0 | 0.07062 |
| controller | C102 | [C14663](https://jlcpcb.com/partdetail/C14663) | sí | geometry_match | 0 | 0.0000 | 0.0000 | 90.0 | 0.07396 |
| controller | C103 | [C14663](https://jlcpcb.com/partdetail/C14663) | sí | geometry_match | 0 | 0.0000 | 0.0000 | 180.0 | 0.07396 |
| controller | C104 | [C14663](https://jlcpcb.com/partdetail/C14663) | sí | geometry_match | 0 | 0.0000 | 0.0000 | 90.0 | 0.07396 |
| controller | C105 | [C14663](https://jlcpcb.com/partdetail/C14663) | sí | geometry_match | 0 | 0.0000 | 0.0000 | 90.0 | 0.07396 |
| controller | C106 | [C19666](https://jlcpcb.com/partdetail/C19666) | sí | geometry_match | 0 | 0.0000 | 0.0000 | 90.0 | 0.07396 |
| controller | C107 | [C57112](https://jlcpcb.com/partdetail/C57112) | sí | geometry_match | 0 | 0.0000 | 0.0000 | 270.0 | 0.07396 |
| controller | C108 | [C15849](https://jlcpcb.com/partdetail/C15849) | sí | geometry_match | 0 | 0.0000 | 0.0000 | 180.0 | 0.07396 |
| controller | C109 | [C14663](https://jlcpcb.com/partdetail/C14663) | sí | geometry_match | 0 | 0.0000 | 0.0000 | 180.0 | 0.07396 |
| controller | C110 | [C15849](https://jlcpcb.com/partdetail/C15849) | sí | geometry_match | 0 | 0.0000 | 0.0000 | 180.0 | 0.07396 |
| controller | C111 | [C14663](https://jlcpcb.com/partdetail/C14663) | sí | geometry_match | 0 | 0.0000 | 0.0000 | 180.0 | 0.07396 |
| controller | C202 | [C14663](https://jlcpcb.com/partdetail/C14663) | sí | geometry_match | 0 | 0.0000 | 0.0000 | 90.0 | 0.07396 |
| controller | C203 | [C96446](https://jlcpcb.com/partdetail/C96446) | sí | geometry_match | 0 | 0.0000 | 0.0000 | 90.0 | 0.07396 |
| controller | F301 | [C2838907](https://jlcpcb.com/partdetail/C2838907) | sí | geometry_match | 0 | 0.0000 | 0.0000 | 0.0 | 0.04526 |
| controller | D301 | [C2909963](https://jlcpcb.com/partdetail/C2909963) | sí | geometry_match | 0 | 0.0000 | 0.0000 | 0.0 | 0.00025 |
| controller | F305 | [C2838907](https://jlcpcb.com/partdetail/C2838907) | sí | geometry_match | 0 | 0.0000 | 0.0000 | 0.0 | 0.04526 |
| controller | D307 | [C2909963](https://jlcpcb.com/partdetail/C2909963) | sí | geometry_match | 0 | 0.0000 | 0.0000 | 180.0 | 0.00025 |
| controller | D302 | [C148216](https://jlcpcb.com/partdetail/C148216) | sí | geometry_match | 0 | 0.0000 | 0.0000 | 0.0 | 0.19964 |
| controller | C301 | [C15850](https://jlcpcb.com/partdetail/C15850) | sí | geometry_match | 0 | 0.0000 | 0.0000 | 0.0 | 0.05076 |
| controller | C302 | [C14663](https://jlcpcb.com/partdetail/C14663) | sí | geometry_match | 0 | 0.0000 | 0.0000 | 0.0 | 0.07396 |
| controller | C315 | [C89632](https://jlcpcb.com/partdetail/C89632) | sí | geometry_match | 0 | 0.0000 | 0.0000 | 0.0 | 0.11758 |
| controller | U301 | [C780769](https://jlcpcb.com/partdetail/C780769) | sí | geometry_match | 270 | 0.0000 | 0.0000 | 270.0 | 0.06138 |
| controller | C303 | [C14663](https://jlcpcb.com/partdetail/C14663) | sí | geometry_match | 0 | 0.0000 | 0.0000 | 0.0 | 0.07396 |
| controller | L301 | [C19947652](https://jlcpcb.com/partdetail/C19947652) | sí | geometry_match | 0 | 0.0000 | 0.0000 | 0.0 | 0.09956 |
| controller | C304 | [C380338](https://jlcpcb.com/partdetail/C380338) | sí | geometry_match | 0 | 0.0000 | 0.0000 | 0.0 | 0.05076 |
| controller | C305 | [C380338](https://jlcpcb.com/partdetail/C380338) | sí | geometry_match | 0 | 0.0000 | 0.0000 | 0.0 | 0.05076 |
| controller | C306 | [C14663](https://jlcpcb.com/partdetail/C14663) | sí | geometry_match | 0 | 0.0000 | 0.0000 | 0.0 | 0.07396 |
| controller | U302 | [C55266](https://jlcpcb.com/partdetail/C55266) | sí | geometry_match | 180 | 0.0000 | 0.0000 | 270.0 | 0.21251 |
| controller | R301 | [C25803](https://jlcpcb.com/partdetail/C25803) | sí | geometry_match | 0 | 0.0000 | 0.0000 | 180.0 | 0.07062 |
| controller | R304 | [C23184](https://jlcpcb.com/partdetail/C23184) | sí | geometry_match | 0 | 0.0000 | 0.0000 | 90.0 | 0.07062 |
| controller | R305 | [C21190](https://jlcpcb.com/partdetail/C21190) | sí | geometry_match | 0 | 0.0000 | 0.0000 | 270.0 | 0.07062 |
| controller | C308 | [C15849](https://jlcpcb.com/partdetail/C15849) | sí | geometry_match | 0 | 0.0000 | 0.0000 | 270.0 | 0.07396 |
| controller | C309 | [C96446](https://jlcpcb.com/partdetail/C96446) | sí | geometry_match | 0 | 0.0000 | 0.0000 | 90.0 | 0.07396 |
| controller | J110 | [C2689964](https://jlcpcb.com/partdetail/C2689964) | sí | geometry_match | 0 | 0.0013 | 0.0000 | 0.0 | 0.01545 |
| controller | U203 | [C7519](https://jlcpcb.com/partdetail/C7519) | sí | geometry_match | 270 | 0.0000 | 0.0000 | 90.0 | 0.01058 |
| controller | R221 | [C23140](https://jlcpcb.com/partdetail/C23140) | sí | geometry_match | 0 | 0.0000 | 0.0000 | 0.0 | 0.07062 |
| controller | R222 | [C23140](https://jlcpcb.com/partdetail/C23140) | sí | geometry_match | 0 | 0.0000 | 0.0000 | 0.0 | 0.07062 |
| controller | R223 | [C23186](https://jlcpcb.com/partdetail/C23186) | sí | geometry_match | 0 | 0.0000 | 0.0000 | 270.0 | 0.07062 |
| controller | R224 | [C23186](https://jlcpcb.com/partdetail/C23186) | sí | geometry_match | 0 | 0.0000 | 0.0000 | 0.0 | 0.07062 |
| controller | R225 | [C25803](https://jlcpcb.com/partdetail/C25803) | sí | geometry_match | 0 | 0.0000 | 0.0000 | 0.0 | 0.07062 |
| controller | R226 | [C25803](https://jlcpcb.com/partdetail/C25803) | sí | geometry_match | 0 | 0.0000 | 0.0000 | 90.0 | 0.07062 |
| controller | C204 | [C57112](https://jlcpcb.com/partdetail/C57112) | sí | geometry_match | 0 | 0.0000 | 0.0000 | 0.0 | 0.07396 |
| controller | C205 | [C15849](https://jlcpcb.com/partdetail/C15849) | sí | geometry_match | 0 | 0.0000 | 0.0000 | 0.0 | 0.07396 |
| controller | F302 | [C163512](https://jlcpcb.com/partdetail/C163512) | sí | geometry_match | 0 | 0.0000 | 0.0000 | 0.0 | 0.04526 |
| controller | J111 | — | excluido | no_model | — | 0.0000 | 0.0000 | 0.0 | — |
| controller | D303 | [C2909963](https://jlcpcb.com/partdetail/C2909963) | sí | geometry_match | 0 | 0.0000 | 0.0000 | 0.0 | 0.00025 |
| controller | J105 | [C382532](https://jlcpcb.com/partdetail/C382532) | sí | geometry_match | 180 | -1.2500 | 0.0000 | 0.0 | 0.00032 |
| controller | R401 | [C23162](https://jlcpcb.com/partdetail/C23162) | sí | geometry_match | 0 | 0.0000 | 0.0000 | 90.0 | 0.07062 |
| controller | R402 | [C21190](https://jlcpcb.com/partdetail/C21190) | sí | geometry_match | 0 | 0.0000 | 0.0000 | 90.0 | 0.07062 |
| controller | C401 | [C14663](https://jlcpcb.com/partdetail/C14663) | sí | geometry_match | 0 | 0.0000 | 0.0000 | 90.0 | 0.07396 |
| controller | R413 | [C2086379](https://jlcpcb.com/partdetail/C2086379) | sí | geometry_match | 0 | 0.0000 | 0.0000 | 180.0 | 0.01578 |
| controller | C408 | [C14663](https://jlcpcb.com/partdetail/C14663) | sí | geometry_match | 0 | 0.0000 | 0.0000 | 0.0 | 0.07396 |
| controller | J106 | [C382533](https://jlcpcb.com/partdetail/C382533) | excluido | geometry_match | 180 | 2.5000 | 0.0000 | 180.0 | 0.00064 |
| controller | R403 | [C23162](https://jlcpcb.com/partdetail/C23162) | sí | geometry_match | 0 | 0.0000 | 0.0000 | 0.0 | 0.07062 |
| controller | R404 | [C21190](https://jlcpcb.com/partdetail/C21190) | sí | geometry_match | 0 | 0.0000 | 0.0000 | 180.0 | 0.07062 |
| controller | C402 | [C57112](https://jlcpcb.com/partdetail/C57112) | sí | geometry_match | 0 | 0.0000 | 0.0000 | 0.0 | 0.07396 |
| controller | J107 | [C382532](https://jlcpcb.com/partdetail/C382532) | sí | geometry_match | 180 | 0.0000 | -1.2500 | 90.0 | 0.00032 |
| controller | R405 | [C25804](https://jlcpcb.com/partdetail/C25804) | sí | geometry_match | 0 | 0.0000 | 0.0000 | 270.0 | 0.07062 |
| controller | R406 | [C21190](https://jlcpcb.com/partdetail/C21190) | sí | geometry_match | 0 | 0.0000 | 0.0000 | 270.0 | 0.07062 |
| controller | C403 | [C14663](https://jlcpcb.com/partdetail/C14663) | sí | geometry_match | 0 | 0.0000 | 0.0000 | 90.0 | 0.07396 |
| controller | J108 | [C476906](https://jlcpcb.com/partdetail/C476906) | excluido | geometry_match | 180 | 0.0000 | 8.7500 | 270.0 | 0.0016 |
| controller | R407 | [C25804](https://jlcpcb.com/partdetail/C25804) | sí | geometry_match | 0 | 0.0000 | 0.0000 | 90.0 | 0.07062 |
| controller | R408 | [C21190](https://jlcpcb.com/partdetail/C21190) | sí | geometry_match | 0 | 0.0000 | 0.0000 | 270.0 | 0.07062 |
| controller | C404 | [C14663](https://jlcpcb.com/partdetail/C14663) | sí | geometry_match | 0 | 0.0000 | 0.0000 | 90.0 | 0.07396 |
| controller | R409 | [C25804](https://jlcpcb.com/partdetail/C25804) | sí | geometry_match | 0 | 0.0000 | 0.0000 | 90.0 | 0.07062 |
| controller | R410 | [C21190](https://jlcpcb.com/partdetail/C21190) | sí | geometry_match | 0 | 0.0000 | 0.0000 | 270.0 | 0.07062 |
| controller | C405 | [C14663](https://jlcpcb.com/partdetail/C14663) | sí | geometry_match | 0 | 0.0000 | 0.0000 | 90.0 | 0.07396 |
| controller | U304 | [C55266](https://jlcpcb.com/partdetail/C55266) | sí | geometry_match | 180 | 0.0000 | 0.0000 | 180.0 | 0.21251 |
| controller | R306 | [C22952](https://jlcpcb.com/partdetail/C22952) | sí | geometry_match | 0 | 0.0000 | 0.0000 | 0.0 | 0.07062 |
| controller | C409 | [C14663](https://jlcpcb.com/partdetail/C14663) | sí | geometry_match | 0 | 0.0000 | 0.0000 | 270.0 | 0.07396 |
| controller | C410 | [C15849](https://jlcpcb.com/partdetail/C15849) | sí | geometry_match | 0 | 0.0000 | 0.0000 | 270.0 | 0.07396 |
| controller | J109 | [C158001](https://jlcpcb.com/partdetail/C158001) | sí | geometry_match | 0 | 1.5000 | 0.0000 | 0.0 | 0.0014 |
| controller | R411 | [C21190](https://jlcpcb.com/partdetail/C21190) | sí | geometry_match | 0 | 0.0000 | 0.0000 | 90.0 | 0.07062 |
| controller | R415 | [C25803](https://jlcpcb.com/partdetail/C25803) | excluido | geometry_match | 0 | 0.0000 | 0.0000 | 0.0 | 0.07062 |
| controller | R416 | [C25803](https://jlcpcb.com/partdetail/C25803) | excluido | geometry_match | 0 | 0.0000 | 0.0000 | 0.0 | 0.07062 |
| controller | C406 | [C57112](https://jlcpcb.com/partdetail/C57112) | sí | geometry_match | 0 | 0.0000 | 0.0000 | 90.0 | 0.07396 |
| controller | R412 | [C21190](https://jlcpcb.com/partdetail/C21190) | sí | geometry_match | 0 | 0.0000 | 0.0000 | 0.0 | 0.07062 |
| controller | C407 | [C14663](https://jlcpcb.com/partdetail/C14663) | sí | geometry_match | 0 | 0.0000 | 0.0000 | 270.0 | 0.07396 |
| controller | J112 | [C158012](https://jlcpcb.com/partdetail/C158012) | sí | geometry_match | 180 | 1.2500 | 0.0000 | 180.0 | 0.00032 |
| controller | F306 | [C2838912](https://jlcpcb.com/partdetail/C2838912) | sí | no_model | — | 0.0000 | 0.0000 | -90.0 | — |
| controller | D308 | [C2909963](https://jlcpcb.com/partdetail/C2909963) | sí | geometry_match | 0 | 0.0000 | 0.0000 | 90.0 | 0.00025 |
| controller | F303 | [C2838907](https://jlcpcb.com/partdetail/C2838907) | sí | geometry_match | 0 | 0.0000 | 0.0000 | 180.0 | 0.04526 |
| controller | D304 | [C2909963](https://jlcpcb.com/partdetail/C2909963) | sí | geometry_match | 0 | 0.0000 | 0.0000 | 180.0 | 0.00025 |
| controller | C501 | [C176683](https://jlcpcb.com/partdetail/C176683) | sí | geometry_match | 180 | 0.0000 | 0.0000 | 90.0 | 0.14476 |
| controller | C502 | [C14663](https://jlcpcb.com/partdetail/C14663) | sí | geometry_match | 0 | 0.0000 | 0.0000 | 180.0 | 0.07396 |
| controller | U501 | [C575551](https://jlcpcb.com/partdetail/C575551) | sí | geometry_match | 270 | 0.0000 | 0.0000 | 180.0 | 0.00241 |
| controller | C503 | [C14663](https://jlcpcb.com/partdetail/C14663) | sí | geometry_match | 0 | 0.0000 | 0.0000 | 180.0 | 0.07396 |
| controller | C504 | [C77571](https://jlcpcb.com/partdetail/C77571) | sí | geometry_match | 0 | 0.0000 | 0.0000 | 0.0 | 0.07396 |
| controller | R501 | [C23140](https://jlcpcb.com/partdetail/C23140) | sí | geometry_match | 0 | 0.0000 | 0.0000 | 180.0 | 0.07062 |
| controller | R502 | [C25804](https://jlcpcb.com/partdetail/C25804) | sí | geometry_match | 0 | 0.0000 | 0.0000 | 0.0 | 0.07062 |
| controller | R503 | [C23140](https://jlcpcb.com/partdetail/C23140) | sí | geometry_match | 0 | 0.0000 | 0.0000 | 180.0 | 0.07062 |
| controller | R504 | [C25804](https://jlcpcb.com/partdetail/C25804) | sí | geometry_match | 0 | 0.0000 | 0.0000 | 0.0 | 0.07062 |
| controller | R505 | [C23140](https://jlcpcb.com/partdetail/C23140) | sí | geometry_match | 0 | 0.0000 | 0.0000 | 180.0 | 0.07062 |
| controller | R506 | [C25804](https://jlcpcb.com/partdetail/C25804) | sí | geometry_match | 0 | 0.0000 | 0.0000 | 0.0 | 0.07062 |
| controller | R507 | [C25804](https://jlcpcb.com/partdetail/C25804) | sí | geometry_match | 0 | 0.0000 | 0.0000 | 180.0 | 0.07062 |
| controller | R508 | [C25810](https://jlcpcb.com/partdetail/C25810) | sí | geometry_match | 0 | 0.0000 | 0.0000 | 180.0 | 0.07062 |
| controller | R509 | [C23184](https://jlcpcb.com/partdetail/C23184) | sí | geometry_match | 0 | 0.0000 | 0.0000 | 0.0 | 0.07062 |
| controller | C505 | [C14663](https://jlcpcb.com/partdetail/C14663) | sí | geometry_match | 0 | 0.0000 | 0.0000 | 0.0 | 0.07396 |
| controller | R510 | [C22940](https://jlcpcb.com/partdetail/C22940) | sí | geometry_match | 0 | 0.0000 | 0.0000 | 0.0 | 0.07062 |
| controller | C506 | [C57112](https://jlcpcb.com/partdetail/C57112) | sí | geometry_match | 0 | 0.0000 | 0.0000 | 0.0 | 0.07396 |
| controller | J113 | [C382535](https://jlcpcb.com/partdetail/C382535) | sí | geometry_match | 180 | -5.0000 | 0.0000 | 0.0 | 0.00127 |
| controller | F304 | [C2838907](https://jlcpcb.com/partdetail/C2838907) | sí | geometry_match | 0 | 0.0000 | 0.0000 | 0.0 | 0.04526 |
| controller | D305 | [C2909963](https://jlcpcb.com/partdetail/C2909963) | sí | geometry_match | 0 | 0.0000 | 0.0000 | 180.0 | 0.00025 |
| controller | D306 | [C2909963](https://jlcpcb.com/partdetail/C2909963) | sí | geometry_match | 0 | 0.0000 | 0.0000 | 0.0 | 0.00025 |
| controller | U502 | [C99395](https://jlcpcb.com/partdetail/C99395) | sí | geometry_match | 180 | 0.0000 | 0.0000 | 180.0 | 0.16298 |
| controller | Q501 | [C347491](https://jlcpcb.com/partdetail/C347491) | sí | geometry_match | 180 | 0.0000 | 0.0000 | 180.0 | 0.06326 |
| controller | R511 | [C23140](https://jlcpcb.com/partdetail/C23140) | sí | geometry_match | 0 | 0.0000 | 0.0000 | 0.0 | 0.07062 |
| controller | R512 | [C25804](https://jlcpcb.com/partdetail/C25804) | sí | geometry_match | 0 | 0.0000 | 0.0000 | 0.0 | 0.07062 |
| controller | R513 | [C23140](https://jlcpcb.com/partdetail/C23140) | sí | geometry_match | 0 | 0.0000 | 0.0000 | 0.0 | 0.07062 |
| controller | R514 | [C25803](https://jlcpcb.com/partdetail/C25803) | sí | geometry_match | 0 | 0.0000 | 0.0000 | 0.0 | 0.07062 |
| controller | C507 | [C14663](https://jlcpcb.com/partdetail/C14663) | sí | geometry_match | 0 | 0.0000 | 0.0000 | 180.0 | 0.07396 |
| controller | C508 | [C15849](https://jlcpcb.com/partdetail/C15849) | sí | geometry_match | 0 | 0.0000 | 0.0000 | 0.0 | 0.07396 |
| controller | U601 | [C20032](https://jlcpcb.com/partdetail/C20032) | sí | geometry_match | 180 | 0.0000 | 0.0000 | 180.0 | 0.16298 |
| controller | U602 | [C352973](https://jlcpcb.com/partdetail/C352973) | sí | geometry_match | 270 | 0.0000 | 0.0000 | 270.0 | 0.20119 |
| controller | R601 | [C23140](https://jlcpcb.com/partdetail/C23140) | sí | geometry_match | 0 | 0.0000 | 0.0000 | 0.0 | 0.07062 |
| controller | R602 | [C21190](https://jlcpcb.com/partdetail/C21190) | sí | geometry_match | 0 | 0.0000 | 0.0000 | 0.0 | 0.07062 |
| controller | R603 | [C25804](https://jlcpcb.com/partdetail/C25804) | sí | geometry_match | 0 | 0.0000 | 0.0000 | 180.0 | 0.07062 |
| controller | R604 | [C25804](https://jlcpcb.com/partdetail/C25804) | sí | geometry_match | 0 | 0.0000 | 0.0000 | 0.0 | 0.07062 |
| controller | C601 | [C14663](https://jlcpcb.com/partdetail/C14663) | sí | geometry_match | 0 | 0.0000 | 0.0000 | 0.0 | 0.07396 |
| controller | C602 | [C14663](https://jlcpcb.com/partdetail/C14663) | sí | geometry_match | 0 | 0.0000 | 0.0000 | 0.0 | 0.07396 |
| controller | U605 | [C7836](https://jlcpcb.com/partdetail/C7836) | sí | geometry_match | 180 | 0.0000 | 0.0000 | 180.0 | 0.16298 |
| controller | C605 | [C14663](https://jlcpcb.com/partdetail/C14663) | sí | geometry_match | 0 | 0.0000 | 0.0000 | 0.0 | 0.07396 |
| controller | U606 | [C403723](https://jlcpcb.com/partdetail/C403723) | sí | geometry_match | 270 | 0.0045 | 0.0000 | 270.0 | 0.01566 |
| controller | C606 | [C14663](https://jlcpcb.com/partdetail/C14663) | sí | geometry_match | 0 | 0.0000 | 0.0000 | 180.0 | 0.07396 |
| controller | R701 | [C25803](https://jlcpcb.com/partdetail/C25803) | sí | geometry_match | 0 | 0.0000 | 0.0000 | 270.0 | 0.07062 |
| controller | R702 | [C25803](https://jlcpcb.com/partdetail/C25803) | sí | geometry_match | 0 | 0.0000 | 0.0000 | 270.0 | 0.07062 |
| controller | R703 | [C25804](https://jlcpcb.com/partdetail/C25804) | sí | geometry_match | 0 | 0.0000 | 0.0000 | 0.0 | 0.07062 |
| controller | C701 | [C14663](https://jlcpcb.com/partdetail/C14663) | sí | geometry_match | 0 | 0.0000 | 0.0000 | 0.0 | 0.07396 |
| controller | R704 | [C25803](https://jlcpcb.com/partdetail/C25803) | sí | geometry_match | 0 | 0.0000 | 0.0000 | 90.0 | 0.07062 |
| controller | R705 | [C25803](https://jlcpcb.com/partdetail/C25803) | sí | geometry_match | 0 | 0.0000 | 0.0000 | 90.0 | 0.07062 |
| controller | R706 | [C25804](https://jlcpcb.com/partdetail/C25804) | sí | geometry_match | 0 | 0.0000 | 0.0000 | 180.0 | 0.07062 |
| controller | C702 | [C14663](https://jlcpcb.com/partdetail/C14663) | sí | geometry_match | 0 | 0.0000 | 0.0000 | 180.0 | 0.07396 |
| controller | R723 | [C25804](https://jlcpcb.com/partdetail/C25804) | sí | geometry_match | 0 | 0.0000 | 0.0000 | 90.0 | 0.07062 |
| controller | R724 | [C25804](https://jlcpcb.com/partdetail/C25804) | sí | geometry_match | 0 | 0.0000 | 0.0000 | 0.0 | 0.07062 |
| controller | R725 | [C25804](https://jlcpcb.com/partdetail/C25804) | sí | geometry_match | 0 | 0.0000 | 0.0000 | 90.0 | 0.07062 |
| controller | J114 | [C52016393](https://jlcpcb.com/partdetail/C52016393) | sí | geometry_match | 270 | 6.3500 | 0.0000 | 0.0 | 0.0 |
| controller | RT701 | [C13564](https://jlcpcb.com/partdetail/C13564) | sí | geometry_match | 0 | 0.0000 | 0.0000 | 180.0 | 0.07062 |
| controller | R726 | [C25804](https://jlcpcb.com/partdetail/C25804) | sí | geometry_match | 0 | 0.0000 | 0.0000 | 0.0 | 0.07062 |
| controller | C704 | [C14663](https://jlcpcb.com/partdetail/C14663) | sí | geometry_match | 0 | 0.0000 | 0.0000 | 180.0 | 0.07396 |
| controller | J115 | — | excluido | no_model | — | 0.0000 | 0.0000 | 0.0 | — |
| controller | C708 | — | excluido | no_model | — | 0.0000 | 0.0000 | 0.0 | — |
| controller | J116 | [C2149727](https://jlcpcb.com/partdetail/C2149727) | sí | geometry_match | 270 | 0.0000 | 0.0000 | 270.0 | 0.00115 |
| controller | J117 | — | excluido | no_model | — | 0.0000 | 0.0000 | 0.0 | — |
| controller | J118 | [C5169636](https://jlcpcb.com/partdetail/C5169636) | sí | review_geometry | — | 0.0000 | 0.0000 | 0.0 | 2.50032 |
| controller | J119 | [C575074](https://jlcpcb.com/partdetail/C575074) | sí | geometry_match | 90 | 0.0000 | 0.0000 | 90.0 | 0.0 |
| controller | J120 | [C575074](https://jlcpcb.com/partdetail/C575074) | sí | geometry_match | 90 | 0.0000 | 0.0000 | 90.0 | 0.0 |
| controller | F701 | [C142789](https://jlcpcb.com/partdetail/C142789) | sí | review_geometry | — | 0.0000 | 0.0000 | 180.0 | 0.9992 |
| controller | RV701 | [C7502584](https://jlcpcb.com/partdetail/C7502584) | sí | geometry_match | 0 | 3.7500 | -1.1000 | 0.0 | 0.2491 |
| controller | C707 | [C161105](https://jlcpcb.com/partdetail/C161105) | sí | geometry_match | 0 | 0.0000 | 0.0000 | 180.0 | 0.29988 |
| controller | F702 | [C142716](https://jlcpcb.com/partdetail/C142716) | sí | no_model | — | 0.0000 | 0.0000 | 0.0 | — |
| controller | PS701 | [C6280124](https://jlcpcb.com/partdetail/C6280124) | sí | geometry_match | 0 | -10.5000 | 0.0000 | 90.0 | 0.00102 |
| controller | J121 | — | excluido | no_model | — | 0.0000 | 0.0000 | 180.0 | — |
| controller | U303 | [C2158003](https://jlcpcb.com/partdetail/C2158003) | sí | geometry_match | 180 | 0.0000 | 0.0000 | 180.0 | 0.06265 |
| controller | L302 | [C2687402](https://jlcpcb.com/partdetail/C2687402) | sí | datasheet_checked | 180 | 0.0000 | 0.0000 | 180.0 | 0.55414 |
| controller | C310 | [C138687](https://jlcpcb.com/partdetail/C138687) | sí | geometry_match | 0 | 0.0000 | 0.0000 | 0.0 | 0.04138 |
| controller | C316 | [C14663](https://jlcpcb.com/partdetail/C14663) | sí | geometry_match | 0 | 0.0000 | 0.0000 | 0.0 | 0.07396 |
| controller | C311 | [C49118556](https://jlcpcb.com/partdetail/C49118556) | sí | geometry_match | 0 | 0.0000 | 0.0000 | 90.0 | 0.04138 |
| controller | C312 | [C49118556](https://jlcpcb.com/partdetail/C49118556) | sí | geometry_match | 0 | 0.0000 | 0.0000 | 90.0 | 0.04138 |
| controller | C313 | [C14663](https://jlcpcb.com/partdetail/C14663) | sí | geometry_match | 0 | 0.0000 | 0.0000 | 270.0 | 0.07396 |
| controller | R302 | [C23137](https://jlcpcb.com/partdetail/C23137) | sí | geometry_match | 0 | 0.0000 | 0.0000 | 0.0 | 0.07062 |
| controller | R303 | [C23352](https://jlcpcb.com/partdetail/C23352) | sí | geometry_match | 0 | 0.0000 | 0.0000 | 180.0 | 0.07062 |
| controller | C314 | [C49326334](https://jlcpcb.com/partdetail/C49326334) | sí | no_model | — | 0.0000 | 0.0000 | 0.0 | — |
| controller | U603 | [C352973](https://jlcpcb.com/partdetail/C352973) | sí | geometry_match | 270 | 0.0000 | 0.0000 | 90.0 | 0.20119 |
| controller | Q701 | [C82045](https://jlcpcb.com/partdetail/C82045) | sí | geometry_match | 180 | 0.0000 | 0.0000 | 180.0 | 0.29694 |
| controller | C603 | [C14663](https://jlcpcb.com/partdetail/C14663) | sí | geometry_match | 0 | 0.0000 | 0.0000 | 0.0 | 0.07396 |
| controller | R722 | [C25804](https://jlcpcb.com/partdetail/C25804) | sí | geometry_match | 0 | 0.0000 | 0.0000 | 270.0 | 0.07062 |
| controller | R801 | [C23140](https://jlcpcb.com/partdetail/C23140) | sí | geometry_match | 0 | 0.0000 | 0.0000 | 180.0 | 0.07062 |
| controller | R802 | [C25803](https://jlcpcb.com/partdetail/C25803) | sí | geometry_match | 0 | 0.0000 | 0.0000 | 0.0 | 0.07062 |
| controller | D701 | [C2909963](https://jlcpcb.com/partdetail/C2909963) | sí | geometry_match | 0 | 0.0000 | 0.0000 | 90.0 | 0.00025 |
| controller | K701 | [C397236](https://jlcpcb.com/partdetail/C397236) | sí | review_geometry | — | 0.0000 | 0.0000 | 180.0 | 2.50061 |
| controller | R711 | [C25804](https://jlcpcb.com/partdetail/C25804) | sí | geometry_match | 0 | 0.0000 | 0.0000 | 180.0 | 0.07062 |
| controller | R707 | [C23140](https://jlcpcb.com/partdetail/C23140) | sí | geometry_match | 0 | 0.0000 | 0.0000 | 0.0 | 0.07062 |
| controller | R708 | [C25803](https://jlcpcb.com/partdetail/C25803) | sí | geometry_match | 0 | 0.0000 | 0.0000 | 180.0 | 0.07062 |
| controller | Q705 | [C82045](https://jlcpcb.com/partdetail/C82045) | sí | geometry_match | 180 | 0.0000 | 0.0000 | 180.0 | 0.29694 |
| controller | R709 | [C2653986](https://jlcpcb.com/partdetail/C2653986) | sí | geometry_match | 0 | 0.0000 | 0.0000 | 0.0 | 0.07062 |
| controller | U701 | [C10797](https://jlcpcb.com/partdetail/C10797) | sí | geometry_match | 270 | 3.8100 | -2.5400 | 270.0 | 0.0 |
| controller | R710 | [C2086379](https://jlcpcb.com/partdetail/C2086379) | sí | geometry_match | 0 | 0.0000 | 0.0000 | 180.0 | 0.01578 |
| controller | Q703 | [C15293](https://jlcpcb.com/partdetail/C15293) | sí | geometry_match | 0 | 2.5400 | 0.0000 | 0.0 | 0.00508 |
| controller | R713 | [C25804](https://jlcpcb.com/partdetail/C25804) | sí | geometry_match | 0 | 0.0000 | 0.0000 | 270.0 | 0.07062 |
| controller | U604 | [C352973](https://jlcpcb.com/partdetail/C352973) | sí | geometry_match | 270 | 0.0000 | 0.0000 | 270.0 | 0.20119 |
| controller | C604 | [C14663](https://jlcpcb.com/partdetail/C14663) | sí | geometry_match | 0 | 0.0000 | 0.0000 | 270.0 | 0.07396 |
| controller | R714 | [C23140](https://jlcpcb.com/partdetail/C23140) | sí | geometry_match | 0 | 0.0000 | 0.0000 | 0.0 | 0.07062 |
| controller | R715 | [C25803](https://jlcpcb.com/partdetail/C25803) | sí | geometry_match | 0 | 0.0000 | 0.0000 | 180.0 | 0.07062 |
| controller | Q706 | [C82045](https://jlcpcb.com/partdetail/C82045) | sí | geometry_match | 180 | 0.0000 | 0.0000 | 180.0 | 0.29694 |
| controller | R716 | [C2653986](https://jlcpcb.com/partdetail/C2653986) | sí | geometry_match | 0 | 0.0000 | 0.0000 | 270.0 | 0.07062 |
| controller | U702 | [C10797](https://jlcpcb.com/partdetail/C10797) | sí | geometry_match | 270 | 3.8100 | -2.5400 | 270.0 | 0.0 |
| controller | R712 | [C2086379](https://jlcpcb.com/partdetail/C2086379) | sí | geometry_match | 0 | 0.0000 | 0.0000 | 180.0 | 0.01578 |
| controller | Q704 | [C15293](https://jlcpcb.com/partdetail/C15293) | sí | geometry_match | 0 | 2.5400 | 0.0000 | 0.0 | 0.00508 |
| controller | C705 | — | excluido | no_model | — | 0.0000 | 0.0000 | 90.0 | — |
| controller | R727 | — | excluido | no_model | — | 0.0000 | 0.0000 | -90.0 | — |
| controller | R717 | [C25804](https://jlcpcb.com/partdetail/C25804) | sí | geometry_match | 0 | 0.0000 | 0.0000 | 270.0 | 0.07062 |
| controller | R718 | [C23140](https://jlcpcb.com/partdetail/C23140) | sí | geometry_match | 0 | 0.0000 | 0.0000 | 270.0 | 0.07062 |
| controller | R719 | [C25803](https://jlcpcb.com/partdetail/C25803) | sí | geometry_match | 0 | 0.0000 | 0.0000 | 0.0 | 0.07062 |
| controller | Q707 | [C82045](https://jlcpcb.com/partdetail/C82045) | sí | geometry_match | 180 | 0.0000 | 0.0000 | 180.0 | 0.29694 |
| controller | R720 | [C2653986](https://jlcpcb.com/partdetail/C2653986) | sí | geometry_match | 0 | 0.0000 | 0.0000 | 0.0 | 0.07062 |
| controller | U703 | [C10797](https://jlcpcb.com/partdetail/C10797) | sí | geometry_match | 270 | 3.8100 | -2.5400 | 270.0 | 0.0 |
| controller | R721 | [C2086379](https://jlcpcb.com/partdetail/C2086379) | sí | geometry_match | 0 | 0.0000 | 0.0000 | 180.0 | 0.01578 |
| controller | Q708 | [C15293](https://jlcpcb.com/partdetail/C15293) | sí | geometry_match | 0 | 2.5400 | 0.0000 | 0.0 | 0.00508 |
| controller | F703 | [C178840](https://jlcpcb.com/partdetail/C178840) | sí | review_geometry | — | 0.0000 | 0.0000 | 0.0 | 11.46048 |
| controller | BR701 | [C840747](https://jlcpcb.com/partdetail/C840747) | sí | geometry_match | 0 | 5.7750 | 0.0000 | 0.0 | 0.06 |
| controller | C706 | — | excluido | no_model | — | 0.0000 | 0.0000 | 90.0 | — |
| controller | R728 | — | excluido | no_model | — | 0.0000 | 0.0000 | -90.0 | — |
| controller | U704 | [C36873216](https://jlcpcb.com/partdetail/C36873216) | sí | geometry_match | 270 | -0.0200 | 0.0000 | 90.0 | 0.14298 |
| controller | C703 | [C14663](https://jlcpcb.com/partdetail/C14663) | sí | geometry_match | 0 | 0.0000 | 0.0000 | 90.0 | 0.07396 |
| front-panel | J1 | [C19103863](https://jlcpcb.com/partdetail/C19103863) | excluido | no_model | — | 0.0000 | 0.0000 | 180.0 | — |
| front-panel | U1 | [C783615](https://jlcpcb.com/partdetail/C783615) | sí | geometry_match | 270 | 0.0000 | 0.0000 | 270.0 | 0.00275 |
| front-panel | C1 | [C14663](https://jlcpcb.com/partdetail/C14663) | sí | geometry_match | 0 | 0.0000 | 0.0000 | 0.0 | 0.07396 |
| front-panel | C2 | [C15849](https://jlcpcb.com/partdetail/C15849) | sí | geometry_match | 0 | 0.0000 | 0.0000 | 0.0 | 0.07396 |
| front-panel | J2 | [C157974](https://jlcpcb.com/partdetail/C157974) | sí | geometry_match | 180 | -7.0000 | 0.0000 | 0.0 | 0.00128 |
| front-panel | R1 | [C23162](https://jlcpcb.com/partdetail/C23162) | sí | geometry_match | 0 | 0.0000 | 0.0000 | 180.0 | 0.07062 |
| front-panel | R2 | [C23162](https://jlcpcb.com/partdetail/C23162) | sí | geometry_match | 0 | 0.0000 | 0.0000 | 180.0 | 0.07062 |
| front-panel | R3 | [C25804](https://jlcpcb.com/partdetail/C25804) | sí | geometry_match | 0 | 0.0000 | 0.0000 | 180.0 | 0.07062 |
| front-panel | R4 | [C25804](https://jlcpcb.com/partdetail/C25804) | sí | geometry_match | 0 | 0.0000 | 0.0000 | 90.0 | 0.07062 |
| front-panel | R5 | [C25804](https://jlcpcb.com/partdetail/C25804) | sí | geometry_match | 0 | 0.0000 | 0.0000 | 90.0 | 0.07062 |
| front-panel | R6 | [C25803](https://jlcpcb.com/partdetail/C25803) | sí | geometry_match | 0 | 0.0000 | 0.0000 | 270.0 | 0.07062 |
| front-panel | C3 | [C96446](https://jlcpcb.com/partdetail/C96446) | sí | geometry_match | 0 | 0.0000 | 0.0000 | 90.0 | 0.07396 |
| front-panel | R11 | [C25804](https://jlcpcb.com/partdetail/C25804) | sí | geometry_match | 0 | 0.0000 | 0.0000 | 270.0 | 0.07062 |
| front-panel | R21 | [C21190](https://jlcpcb.com/partdetail/C21190) | sí | geometry_match | 0 | 0.0000 | 0.0000 | 180.0 | 0.07062 |
| front-panel | SW1 | [C83916](https://jlcpcb.com/partdetail/C83916) | sí | geometry_match | 0 | 0.0000 | 0.0000 | 180.0 | 0.00046 |
| front-panel | C11 | [C14663](https://jlcpcb.com/partdetail/C14663) | sí | geometry_match | 0 | 0.0000 | 0.0000 | 270.0 | 0.07396 |
| front-panel | R12 | [C25804](https://jlcpcb.com/partdetail/C25804) | sí | geometry_match | 0 | 0.0000 | 0.0000 | 270.0 | 0.07062 |
| front-panel | R22 | [C21190](https://jlcpcb.com/partdetail/C21190) | sí | geometry_match | 0 | 0.0000 | 0.0000 | 180.0 | 0.07062 |
| front-panel | SW2 | [C83916](https://jlcpcb.com/partdetail/C83916) | sí | geometry_match | 0 | 0.0000 | 0.0000 | 180.0 | 0.00046 |
| front-panel | C12 | [C14663](https://jlcpcb.com/partdetail/C14663) | sí | geometry_match | 0 | 0.0000 | 0.0000 | 270.0 | 0.07396 |
| front-panel | R13 | [C25804](https://jlcpcb.com/partdetail/C25804) | sí | geometry_match | 0 | 0.0000 | 0.0000 | 270.0 | 0.07062 |
| front-panel | R23 | [C21190](https://jlcpcb.com/partdetail/C21190) | sí | geometry_match | 0 | 0.0000 | 0.0000 | 180.0 | 0.07062 |
| front-panel | SW3 | [C83916](https://jlcpcb.com/partdetail/C83916) | sí | geometry_match | 0 | 0.0000 | 0.0000 | 180.0 | 0.00046 |
| front-panel | C13 | [C14663](https://jlcpcb.com/partdetail/C14663) | sí | geometry_match | 0 | 0.0000 | 0.0000 | 270.0 | 0.07396 |
| front-panel | R14 | [C25804](https://jlcpcb.com/partdetail/C25804) | sí | geometry_match | 0 | 0.0000 | 0.0000 | 270.0 | 0.07062 |
| front-panel | R24 | [C21190](https://jlcpcb.com/partdetail/C21190) | sí | geometry_match | 0 | 0.0000 | 0.0000 | 180.0 | 0.07062 |
| front-panel | SW4 | [C83916](https://jlcpcb.com/partdetail/C83916) | sí | geometry_match | 0 | 0.0000 | 0.0000 | 270.0 | 0.00046 |
| front-panel | C14 | [C14663](https://jlcpcb.com/partdetail/C14663) | sí | geometry_match | 0 | 0.0000 | 0.0000 | 270.0 | 0.07396 |
| front-panel | R15 | [C25804](https://jlcpcb.com/partdetail/C25804) | sí | geometry_match | 0 | 0.0000 | 0.0000 | 270.0 | 0.07062 |
| front-panel | R25 | [C21190](https://jlcpcb.com/partdetail/C21190) | sí | geometry_match | 0 | 0.0000 | 0.0000 | 0.0 | 0.07062 |
| front-panel | SW5 | [C83916](https://jlcpcb.com/partdetail/C83916) | sí | geometry_match | 0 | 0.0000 | 0.0000 | 0.0 | 0.00046 |
| front-panel | C15 | [C14663](https://jlcpcb.com/partdetail/C14663) | sí | geometry_match | 0 | 0.0000 | 0.0000 | 270.0 | 0.07396 |
| front-panel | R16 | [C25804](https://jlcpcb.com/partdetail/C25804) | sí | geometry_match | 0 | 0.0000 | 0.0000 | 270.0 | 0.07062 |
| front-panel | R26 | [C21190](https://jlcpcb.com/partdetail/C21190) | sí | geometry_match | 0 | 0.0000 | 0.0000 | 0.0 | 0.07062 |
| front-panel | SW6 | [C83916](https://jlcpcb.com/partdetail/C83916) | sí | geometry_match | 0 | 0.0000 | 0.0000 | 0.0 | 0.00046 |
| front-panel | C16 | [C14663](https://jlcpcb.com/partdetail/C14663) | sí | geometry_match | 0 | 0.0000 | 0.0000 | 270.0 | 0.07396 |
| front-panel | R17 | [C25804](https://jlcpcb.com/partdetail/C25804) | sí | geometry_match | 0 | 0.0000 | 0.0000 | 270.0 | 0.07062 |
| front-panel | R27 | [C21190](https://jlcpcb.com/partdetail/C21190) | sí | geometry_match | 0 | 0.0000 | 0.0000 | 0.0 | 0.07062 |
| front-panel | SW7 | [C83916](https://jlcpcb.com/partdetail/C83916) | sí | geometry_match | 0 | 0.0000 | 0.0000 | 0.0 | 0.00046 |
| front-panel | C17 | [C14663](https://jlcpcb.com/partdetail/C14663) | sí | geometry_match | 0 | 0.0000 | 0.0000 | 270.0 | 0.07396 |
| front-panel | R7 | [C23179](https://jlcpcb.com/partdetail/C23179) | sí | geometry_match | 0 | 0.0000 | 0.0000 | 0.0 | 0.07062 |
| front-panel | D1 | [C2286](https://jlcpcb.com/partdetail/C2286) | sí | geometry_match | 180 | 0.0000 | 0.0000 | 0.0 | 0.03693 |

## Notas por código LCSC

- **C397236:** BLOCKED: K701 holes span 20 mm; Omron G5RL-1A-E-HR requires 25 mm (20+5). Fix footprint/routing, not CPL. Source: https://omronfs.omron.com/en_US/ecb/products/pdf/en-g5rl.pdf page 5.
- **C5169636:** REVIEW: paired tails differ by 2.5 mm with contact order preserved. Check TE drawing, locating post and harness pin 1; do not rotate to conceal a contact reversal.
- **C142716:** BLOCKED: BOM orders a leadless 0215002.MXP fuse, but PCB footprint is a pair of Littelfuse 111 clips. Clips are not separate BOM items. Resolve assembly BOM/mechanics.
- **C142789:** REVIEW: model lead pitch 25.50 mm versus PCB 27.50 mm; axial leads need forming. Confirm the assembly operation with JLCPCB.
- **C178840:** REVIEW: model is horizontal at 28 mm pitch, PCB is vertical at 5.08 mm. Requires lead forming/manual assembly; rotating a horizontal model cannot validate it.
- **C2687402:** DATASHEET CHECKED: KiCad pads 2.95 x 3.5 mm at +/-2.725 mm give 8.4 mm outer span and 2.5 mm gap, exactly the Bourns recommended layout. The public model uses different pad extensions. Center is unchanged; +180 degrees matches numbered pads (electrically equivalent for this inductor). Source: https://www.bourns.com/data/global/pdfs/SRP7028A.pdf page 1.
- **C2838912:** NO MODEL: public API has no PCB footprint. Nonpolarized 1206 fuse; retained original CPL, pending vendor preview.
- **C49326334:** NO MODEL: public API has no PCB footprint. Nonpolarized 0603 capacitor; retained original CPL, pending vendor preview.
- **C6280124:** Aliases verified by EasyEDA symbol (+V=3,-V=4) and Mean Well IRM-30-SPEC drawing 2026-04-03 page 4; local symbol uses +V=4,-V=3. Pad-envelope center is 10.5 mm from body origin.
- **C83916:** Switch has four physical tails but two electrical contacts; EasyEDA 1/2 map to local 1, 3/4 to local 2.
- **C575074:** Both tails belong to the same conductive FASTON tab. 90 and 270 degrees are electrically/geometrically equivalent; using 90.
- **C2149727:** Two tails per RAST contact: model 1/2->1,3/4->2,5/6->3,7/8->4. NPTH locating post must not shift the electrical pad center.
- **C2689964:** USB shell pad name EP in the vendor model corresponds to SH in KiCad.

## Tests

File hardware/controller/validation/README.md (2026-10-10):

# Validación nativa — controller-core-reva

KiCad 10.0.6. ERC: 0 errores y 0 avisos, sin exclusiones.
Netlist nativa cotejada: 223 componentes, 702 pines.

Configuración estándar de KiCad: no se ejecutan los controles opcionales
footprint_filter, four_way_junction, simulation_model_issue, single_global_label. No se han añadido supresiones.

Alcance: Esquema completo de la principal: núcleo lógico, USB-C de servicio, fuente aislada IRM-30-24, selección de 24 V internos/externos, buck AP63301 de 24 V a 12 V, buck de 3,3 V, sensores, puente H DRV8876, etapa low-side de válvula y etapas de triac de calentador, bomba y molinillo. Un relé G5RL normalmente abierto corta la fase de las cargas y solo se arma mediante reset válido y orden explícita. Las etapas de red no están ensayadas.
No valida mecánica completa, selección eléctrica completa ni fabricación.
Los GPIO sin asignar llevan NC. J105–J108 y J113 son HR A2506WV y J109 una JST ZH B3B-ZR, identificadas por el propietario; falta comprobar el acoplamiento con los mazos. JP16 V1/V2 llegan al puente H y JP3.1/JP3.2 a la etapa de válvula. J112 requiere una fuente de 24 V aislada limitada; corriente, frenado, térmica, liberación de válvula y la salida de JP22 requieren ensayo. El watchdog y sus tiempos también requieren firmware y prueba de banco.

La colocación alinea J104, J108, J107, J113, J109, J105 y J106 con JP21, JP16, JP14, JP3, JP22, JP13 y JP5. JP8, JP19, JP24, JP17, JP1 y JP9 son conectores obligatorios y ya tienen huella: JP19 y JP17 son los TE 1971845-4 y 1971845-3 (RAST 5) y JP8 y JP24 las LEOCO 3941P03 y 5001P02, identificados por el propietario, y los FASTON de PE son TE 63824-1 de dos patas, casados con la foto del propietario. El routing reproducible conecta todas las redes: USB, la entrada de red hasta PS701, K701 y RV701, la salida de 24 V, el puente H, el supervisor con sus interlocks, las etapas de válvula, calentador, bomba y molinillo, los bucks de 12 V y 3,3 V, el frontal, las órdenes a las cargas, el bus de sensores, la telemetría y el ESP32 con el bus del LCD hasta J104: 1441 segmentos y 457 vías, 142 de ellas de cosido. Las fases de carga van duplicadas en F.Cu y B.Cu con cobre de 1 oz; la de las cargas conmutadas, con un bloque de B.Cu bajo el pie del disipador. F.Cu y B.Cu llevan masa en el lado SELV y nada en el de red. La serigrafía lleva el logo, el título y el nombre de cada conector. La barrera de 8 mm red/SELV es una regla DRC y una banda sin cobre en las cuatro capas; el dominio de red es contiguo y reserva el disipador de los tres triacs. DRC con todas las severidades: 0 infracciones y 0 conexiones abiertas; las tres diferencias de paridad son los taladros mecánicos MH1–MH3.

La principal usa cuatro capas, apilado JLC04161H-7628: F.Cu y B.Cu de señal, plano GND_UI en In1.Cu y plano 3V3_CORE en In2.Cu, ambos solo en el lado SELV. Clases explícitas para red, USB, alimentación, conmutación y actuadores. El par USB se calculó para ese apilado (0,29/0,20 mm, 90 Ω); no se pide impedancia controlada.
Regenerar con `python3 tools/validate_kicad.py` desde la raíz.

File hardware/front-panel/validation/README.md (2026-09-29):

# Validación nativa — front-panel-reva

KiCad 10.0.6. ERC: 0 errores y 0 avisos, sin exclusiones.
Netlist nativa cotejada: 42 componentes, 118 pines.

Configuración estándar de KiCad: no se ejecutan los controles opcionales
footprint_filter, four_way_junction, simulation_model_issue, single_global_label. No se han añadido supresiones.

Alcance: Esquema completo del frontal. Declara alimentación externa por J1; no valida la fuente ni la mecánica.
No valida mecánica completa, selección eléctrica completa ni fabricación.
Todas las posiciones tienen huella: SW1–SW7 HRO K2-1102SP-A4SC-04 (OpenSaeco.pretty), J2 JST PH 8 y LED STBY en P7. Contorno y taladros Ø8,4 desde mechanical-source.json.
Regenerar con `python3 tools/validate_kicad.py` desde la raíz.

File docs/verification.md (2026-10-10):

# Verificación de esta base

2026-09-15, Windows, Visual Studio 2022 / MSVC 19.34:
- Comprobación Python de enlaces y receta inactiva: PASS.
- Configuración CMake y compilación host Debug: PASS.
- CTest controller_lockout: 1/1 PASS.
- Páginas PDF 34–37 del manual renderizadas y cotejadas visualmente.
- Fotografías JPEG de la conversación revisadas según docs/HD8911/photos.md.

ESP-IDF no está disponible como comando en esta sesión: build ESP32 no ejecutado.
No se ha compilado para STM32, flasheado placas ni ensayado hardware.
La CI se incluye pero no se ha ejecutado en GitHub.

## Iteración de hardware, 2026-09-16

macOS / AppleClang 21.0.0:
- `python3 tools/check_scaffold.py`: PASS.
- `python3 tools/check_front_panel.py`: PASS; 44 componentes (hoy 42: siete teclas y LED), pinout del TCA9534,
  conectores, filtros, polarización y correspondencia con BOM/netlist prevista.
- CMake/build/CTest: PASS, `controller_lockout` 1/1.
- `git diff --check`: PASS.

El SDK seleccionado por defecto (CommandLineTools/MacOSX27.0) no era compatible
con el linker de Xcode activo. La compilación pasó seleccionando explícitamente
el SDK de ese Xcode, sin cambiar la configuración global del equipo:

```
cmake -S firmware/stm32 -B build/host -DCMAKE_OSX_SYSROOT=/Applications/Xcode.app/Contents/Developer/Platforms/MacOSX.platform/Developer/SDKs/MacOSX26.4.sdk
cmake --build build/host
ctest --test-dir build/host --output-on-failure
```

El comprobador del frontal lee las conexiones del archivo `.kicad_sch` usando
un parser limitado propio. No acredita que el archivo haya sido abierto por
KiCad ni sustituye su ERC. En esa iteración no se había localizado KiCad/kicad-cli; apertura,
exportación nativa de netlist y ERC quedan pendientes. No hay PCB ni DRC.
El SVG auxiliar se revisó como ayuda visual; no es un render nativo de KiCad.
No se ha montado, alimentado o ensayado el circuito.

## Núcleo principal y suministro, 2026-09-16

- Primera hoja de la principal: 32 componentes, STM32G431RBT6 + ESP32-S3-WROOM-1-N8R8.
- `python3 tools/check_controller_core.py`: PASS. Comprueba conexiones de
  alimentación, depuración, arranque, UART y frontal leyendo el esquema generado.
- Coincidencia MPN/código/huella con el catálogo: 28/32 posiciones de la hoja
  principal y 34/44 del frontal. Las restantes son mecánicas sin seleccionar.
- Catálogo: 14 referencias con stock observado en la web renderizada de JLCPCB;
  incluye AP63203 como candidato aún no instanciado. Fecha y fuente por referencia.
- `python3 tools/check_front_panel.py`, enlaces locales y `git diff --check`: PASS.
- Vista SVG auxiliar del núcleo renderizada y revisada. No es exportación de KiCad.

Sigue sin ejecutarse ERC/DRC nativo. No se han generado archivos de fabricación,
hecho pedidos ni reservado componentes. No se repitieron las pruebas del firmware,
que no ha cambiado respecto a la verificación anterior.

## Validación nativa y proyectos KiCad, 2026-09-16 (posterior)

Esta revisión sustituye el estado pendiente de KiCad de los apartados anteriores.
Se ha localizado KiCad 10.0.6 en `/Applications/KiCad`; no estaba en PATH.

- Proyectos `.kicad_pro`, bibliotecas locales y PCB `.kicad_pcb` creados.
- ERC nativo de ambos esquemas: 0 errores y 0 avisos, sin exclusiones añadidas.
  Se documentan los controles opcionales desactivados por defecto.
- Se corrigieron extremos fuera de rejilla, biblioteca ausente y declaración
  de las fuentes externas. La revisión del SVG nativo detectó y corrigió
  etiquetas izquierdas que invadían los símbolos.
- Netlist nativa XML frente a conexiones previstas: 32 componentes / 188 pines
  principal y 44 / 122 frontal, coincidencia completa.
- PCB guardadas y recargadas con `pcbnew`: 28 y 34 huellas respectivamente;
  numeración de pads y conexiones verificadas. Posiciones de trabajo, sin rutas.
- DRC nativo **no aprobado**: principal 60 conexiones, 4 huellas, contorno y 12
  taladros pendientes; frontal 58 conexiones, 10 huellas y contorno pendientes.
  [Detalle e informes](../hardware/kicad-workflow.md).
- El CLI DRC dentro del sandbox abortaba al registrar la aplicación en macOS;
  fuera del sandbox se ejecutó y produjo los informes. No era un DRC aprobado.
- Fotografías IMG_1085/1086/1089 revisadas directamente; tipos constructivos
  registrados, sin asignar referencias comerciales ni cotas a partir de perspectiva.

## Mecánica recuperada de IMG_1098–IMG_1101, 2026-09-17

- Calibre: contorno principal 141,6 × 135,2 mm, incertidumbre estimada ±0,15 mm.
- Fotogrametría calibrada: tres taladros NPTH de aproximadamente 3,5 mm; centros
  registrados con ±0,6 mm en [mecánica de la principal](HD8911/main-board-mechanics.md).
- Contorno y taladros incorporados al `.kicad_pcb`; archivo guardado y recargado
  para verificar las coordenadas. La vista mecánica SVG fue renderizada y revisada.
- DRC posterior: ya no informa contorno ausente. Conserva 12 taladros del pad
  térmico ESP32 fuera de regla, 60 conexiones sin ruta, cuatro conectores sin
  huella y tres huellas mecánicas adicionales al esquema.
- Las fotos no proporcionan espesor o alturas fiables ni tolerancia suficiente
  para fabricar huellas de conectores. Esos campos continúan pendientes.
- El propietario aceptó el 2026-09-17 el contorno y los centros de taladro como
  línea base mecánica de Rev A. La aceptación no libera el resto del diseño.

Sin ampliación de firmware ni ensayos eléctricos. Supervisión, sensores y potencia
de cargas siguen pendientes en el esquema principal.

## Alimentación de baja tensión y conectores internos, 2026-09-17

- La principal pasa de 32 a 48 componentes; los 48 tienen MPN, código JLC/LCSC y huella.
- Entrada J101 de 12 V DC aislados con fusible 1 A, bloqueo de polaridad SS34 y
  TVS SMAJ18A. La fuente AC/DC aislada y certificada aún no está seleccionada.
- U301 AP63203WU-7 implementado a 3,3 V/2 A con 3,9 µH, 10 µF de entrada,
  2×22 µF de salida y bootstrap de 100 nF según la tabla 2 del fabricante.
- U302 TPS22918DBVR implementado para `3V3_UI`, controlado por PB0, con pull-up,
  CT de 1 nF y descarga QOD. Falta medirlo con el display definitivo.
- Existencias observadas y registradas para las nuevas referencias; el inductor
  seleccionado tiene 3,3 A nominales y 3,9 A de saturación.
- Comprobador propio: PASS. ERC KiCad 10.0.6: 0 infracciones; netlist nativa:
  48 componentes y 227 pines, coincidencia completa.
- J101 seleccionado como JST XH lateral de 2 vías; J102/J103 como 1×6 de 2,54 mm;
  J104 y J1 frontal como IDC polarizado 2×8 de 2,54 mm. Stock observado y registrado.
- PCB principal: 48 huellas eléctricas, 16 nuevas de alimentación y cuatro
  conectores colocados provisionalmente;
  contorno y los tres taladros aceptados conservados y verificados tras recargar.
- DRC de la principal: 0 infracciones geométricas/de reglas, 122 conexiones sin
  rutear y 3 avisos de paridad esperados (MH1–MH3 adicionales al esquema).
- PCB frontal: J1 incorporado; 35 huellas, 70 conexiones sin rutear. El DRC solo
  marca el contorno ausente y las nueve huellas mecánicas aún pendientes.
- El mínimo de taladro se fija en 0,20 mm para las vías térmicas del ESP32, valor
  preferido publicado por JLCPCB. No equivale a liberar el stack-up ni la fabricación.

## Diagrama de interconexión del manual, 2026-09-18

- La página PDF 59, capítulo 10, hoja 1/1, se renderizó y cotejó visualmente con
  la transcripción aportada por el propietario. Es un diagrama de interconexión,
  no un esquema de la electrónica interna de la placa.
- Se corrigió el nivel de agua de JP23/2 a **JP22/3**.
- Se confirmaron JP17 (entrada de red), JP1/JP9 (PE), JP19 (calentador), JP24
  (bomba), JP3 (válvula), JP8 (molino), JP13 (temperatura), JP5 (caudalímetro),
  JP16 (motor del grupo y dos micros), JP14 (puerta/cajón) y JP21 (interfaz original).
- JP16 tiene ocho posiciones: dos para motor, dos unidas por puente y dos pares
  para los micros de presencia y posición de trabajo. JP2 aparece expresamente
  sin conectar.
- La comprobación no determina niveles, corrientes, curvas, estados de contactos,
  numeración física ni familias comerciales. Esos datos siguen bloqueando la
  selección final de drivers y huellas del arnés de máquina.

## Identificación de cargas y sensores, 2026-09-18

- Las referencias aportadas se cotejaron con el manual y el despiece HD8911.
  Quedan confirmados: calentador 220–230 V/1900 W, bomba 220–230 V/48 W,
  electroválvula 24 V DC, motor de grupo 24 V DC y molino accionado a 320 V DC
  según el modo de servicio.
- `996530059843` se identificó con el Digmesa FHKSC `932-9521-B`: alimentación
  3,8–20 V, salida NPN de colector abierto y aproximadamente 1925 pulsos/litro.
- La tabla NTC se ajustó únicamente como ayuda de diseño: R25≈49,9 kΩ y B≈4037 K.
  El firmware deberá usar tabla/interpolación y tolerancias del manual.
- Se aclaró que el ajuste de dosis usa la corriente de compresión del motor del
  grupo: I0=100–300 mA y objetivos I0+55/100/200 mA. La corriente del molino se
  mide por separado para detectar falta de grano y bloqueo.
- El módulo capacitivo `421941306721`, el orden de los conectores, los estados de
  micros y las corrientes de bloqueo siguen necesitando caracterización física.

## Entradas pasivas de la principal, 2026-09-18

- La principal pasa de 48 a 68 componentes. Hay 63 posiciones con MPN, código
  JLC/LCSC y huella; J105–J109 quedan sin huella hasta identificar las carcasas.
- JP13 usa un pull-up de 4,7 kΩ, 1 kΩ serie y 100 nF hacia PA0/ADC1_IN1.
- El adaptador de JP5 alimenta el caudalímetro desde `12V_PROTECTED` y acondiciona
  su colector abierto con pull-up a 3,3 V, 1 kΩ serie y 10 nF hacia PA1/TIM2_CH2.
  Esta alimentación solo es válida mientras la entrada lógica siga siendo 12 V.
- JP14 y los dos contactos de JP16 usan entradas activas a cero con 10 kΩ,
  1 kΩ y 100 nF hacia PC0, PC1 y PC2. La secuencia V1–V8 de JP16 procede de la
  vista del manual y no se presenta como numeración física confirmada.
- JP22 y las vías de motor de JP16 se marcan NC explícitamente. No se aplica una
  tensión desconocida al sensor capacitivo ni se anticipa el puente H.
- Comprobador propio: PASS. ERC KiCad 10.0.6: 0 infracciones; netlist nativa:
  68 componentes y 275 pines, coincidencia completa.
- La PCB contiene 63 huellas eléctricas y conserva el contorno y los tres taladros.
  DRC: 0 infracciones geométricas/de reglas, 147 conexiones sin rutear y 8 avisos
  de paridad: J105–J109 y MH1–MH3.

## Medidas de cargas y conectores, 2026-09-18

- Resistencias aportadas por el propietario: molino 68 Ω, electroválvula 56,7 Ω
  y motor del grupo 54,7 Ω. A sus tensiones documentadas dan límites resistivos
  derivados de 4,71 A a 320 V, 0,423 A a 24 V y 0,439 A a 24 V, respectivamente.
  No se presentan como corrientes nominales de los motores.
- JP14 queda abierto si falta puerta o cajón y cerrado únicamente con ambos
  colocados. La red se renombra `DOOR_CLOSED_N`: nivel bajo significa cierre.
- Las fotos con calibre encajan con JST XH 2,50 mm para JP13/JP14/JP5/JP16 y
  JST PH 2,00 mm para JP22. Se seleccionaron cabeceras acodadas genuinas con stock
  LCSC observado, manteniendo el estado candidato hasta probar el acoplamiento.
- La principal incorpora las cinco huellas: 68/68 componentes con MPN, código
  LCSC y huella. JP5 y JP22 permanecen NC por pinout eléctrico desconocido.
- ERC: 0 infracciones, 68 componentes/275 pines. DRC: 0 infracciones geométricas,
  156 conexiones sin rutear y 3 diferencias de paridad correspondientes a MH1–MH3.

## Pinout de caudal y nivel de agua, 2026-09-18

- El propietario confirmó el Digmesa `932-9521-B` y el seguimiento físico de JP5:
  vista cenital, pad cuadrado/pin 1 izquierdo=señal, pin 2=GND y pin 3=VCC.
- La hoja oficial de Digmesa confirma 3,8–20 V, menos de 8 mA y salida NPN de
  colector abierto. JP5 queda alimentado a 12 V y su señal se eleva a 3,3 V antes
  de PA1/TIM2_CH2.
- JP22 usa rojo=VCC, blanco=señal y negro=GND. Se selecciona alimentación a 3,3 V
  y entrada PA2/ADC1_IN3 mediante 1 kΩ/10 nF; la forma de salida y los niveles
  lleno/vacío todavía requieren medida.
- La principal pasa a 70 componentes/279 pines y 70 huellas eléctricas. Comprobador
  propio y ERC nativo: PASS, 0 infracciones. DRC: 0 infracciones geométricas,
  165 conexiones sin rutear y 3 diferencias de paridad correspondientes a MH1–MH3.

## USB-C de servicio, 2026-09-19

- J110 implementa USB 2.0 nativo del ESP32-S3: GPIO19=D−, GPIO20=D+ y GPIO21
  detecta VBUS mediante 100 kΩ/100 kΩ y 10 nF.
- Se seleccionan HRO TYPE-C-31-M-12 (`C165948`), USBLC6-2SC6 (`C7519`), dos
  resistencias CC de 5,1 kΩ y 33 Ω serie en cada línea de datos.
- La alimentación de banco pasa por PTC de 500 mA, puente J111 abierto por defecto
  y SS34 hacia la entrada del buck. No está destinada a cargas ni autoriza conectar
  USB mientras no se haya verificado el aislamiento de la máquina.
- La principal pasa a 83 componentes/324 pines y 83 huellas eléctricas. Comprobador
  propio y ERC KiCad 10.0.6: PASS, 0 infracciones. DRC: 0 infracciones geométricas,
  198 conexiones sin rutear y 3 diferencias de paridad correspondientes a MH1–MH3.
- Las huellas quedan colocadas provisionalmente; el par de 90 Ω, el retorno de masa,
  la envolvente mecánica del conector y la política de pantalla/chasis siguen pendientes
  del routing y revisión física.

## Puente H del motor del grupo, 2026-09-19

- JP16 V1/V2 se asignan a `OUT1/OUT2` de un DRV8876PWPR. PA8 gobierna PWM,
  PA6 dirección, PB5 `nSLEEP`, PB6 `nFAULT` y PA3 adquiere `IPROPI`.
- J112 introduce 24 V DC aislados para pruebas; F303=1 A, D304=SS34 y
  C501=100 µF/35 V forman la entrada provisional. Este rail no se une a J101.
- R510=2,49 kΩ y el divisor R508/R509=16 kΩ/49,9 kΩ producen un límite teórico
  cercano a 1,00 A. IMODE a masa activa recuperación automática; el firmware
  deberá retirar `nSLEEP` al detectar `nFAULT`.
- Comprobador propio y ERC KiCad 10.0.6: PASS, 0 infracciones, 103 componentes y
  379 pines. La PCB contiene 103 huellas; DRC: 0 infracciones geométricas,
  243 conexiones sin rutear y 3 diferencias de paridad por MH1–MH3.
- No se libera la etapa: faltan una fuente de 24 V limitada, medida de corriente
  de marcha/arranque/bloqueo, inversión, frenado, ruido, térmica, bulk y TVS.

## Estudio de la electroválvula, 2026-09-19

- La bobina de 56,7 Ω implica 0,423 A y 10,16 W resistivos a 24 V, coherente con
  la referencia nominal de 10 W.
- Se documenta una [etapa low-side candidata](../hardware/power/valve-driver.md)
  con UCC27517DBVR, MOSFET SI2308A de 60 V, rueda libre y fusible propio.
- El propietario confirma JP3.1 (pad cuadrado) a solenoide.1/+24 V y JP3.2 a
  solenoide.2/retorno 0 V; JP3.3–5 y el terminal GND separado quedan sin conectar.
  La bobina se identifica como OLAB 6000BH/B0DN, 24 V DC/10 W, y mide 0,073 V
  en modo diodo en ambos sentidos: no se detecta supresión interna polarizada.
- Motor y válvula sumarían unos 0,862 A resistivos; F303=1 A no se considera una
  protección común válida sin medir transitorios, arranque y temperatura.

## Etapa de la electroválvula incorporada, 2026-09-19

- J113 reproduce JP3 con JST S5B-XH-A(LF)(SN), `C263757`: pin 1 a +24 V, pin 2
  al retorno conmutado y pines 3–5 NC. Se observaron 8.885 unidades en LCSC.
- F304=1 A y D305 separan la rama desde `24V_ACT_RAW`. D306=SS34 queda como
  rueda libre, con cátodo a +24 V y ánodo al drenador.
- PA7 controla U502 UCC27517DBVR; Q501 SI2308A conmuta el retorno. Las entradas
  y la puerta tienen pull-down, y el driver dispone de 100 nF + 1 µF locales.
- Comprobador propio y ERC KiCad 10.0.6: PASS, 0 infracciones, 115 componentes y
  410 pines. La PCB contiene 115 huellas; DRC: 0 infracciones geométricas,
  265 conexiones sin rutear y 3 diferencias de paridad por MH1–MH3.
- La etapa continúa sin liberar: faltan corriente en caliente, liberación,
  sobretensión de drenador, ruido y térmica con la bobina real y fuente limitada.

## Watchdog e interlock de actuadores, 2026-09-19

- U601 TPS3828-33DBVR (`C20032`) supervisa `3V3_CORE` a 2,93 V nominal y PB4/WDI.
  Su salida open-drain comparte `STM_NRST`; timeout nominal 1,6 s y reset nominal
  200 ms, con límites de hoja de datos de 0,9–2,5 s y 120–300 ms.
- R602=1 kΩ evita que WDI flotante desactive el watchdog. U602 SN74LVC2G08DCTR
  (`C352973`) combina `STM_NRST` con las órdenes de `nSLEEP` y válvula; R603/R604
  mantienen las órdenes inactivas durante reset.
- Existencias observadas: 49.065 unidades de C20032 y 21.000 de C352973. La
  categoría exacta de montaje JLCPCB queda por verificar.
- Comprobador propio y ERC KiCad 10.0.6: PASS, 0 infracciones, 123 componentes y
  435 pines. La PCB contiene 123 huellas; DRC: 0 infracciones geométricas,
  287 conexiones sin rutear y 3 diferencias de paridad por MH1–MH3.
- Falta implementar PB4 en firmware y comprobar con osciloscopio arranque,
  brownout, timeout, rearme y corte efectivo de ambas cargas.

## Candidatos JST VH de potencia, 2026-09-19

- Las fotos con calibre de JP24 encajan con JST VHR-2N: dos vías, paso 3,96 mm
  y 7,86 mm de ancho según el plano oficial. Se reserva S2P-VH(LF)(SN), C160355;
  se observaron 4.955 unidades en LCSC.
- JP8 y JP17 usan dos conductores dentro de una carcasa de tres vías cuya anchura
  encaja con VHR-3N: 11,82 mm. Se reserva S3P-VH(LF)(SN), C264986; JLCPCB mostraba
  4.721 unidades en stock y 4.697 disponibles para pedido.
- Las referencias están en el catálogo pero no en el esquema ni en la BOM. La
  liberación exige probar el arnés real, confirmar retención y cerrar el diseño
  de alta tensión. JP19 permanece sin identificar mecánicamente.

## Arquitectura de alimentación Rev A, 2026-09-19

- Se mantienen J101=12 V y J112=24 V como dos entradas DC externas aisladas y
  limitadas para el banco; USB puede alimentar únicamente lógica mediante el
  puente J111, abierto por defecto.
- Motor y válvula suman 0,862 A/20,69 W según sus resistencias medidas. El límite
  de 1 A del puente H eleva el peor caso provisional de ambas ramas a 1,423 A;
  se especifica una fuente de banco de al menos 1,5 A, preferiblemente 2 A para
  margen de medida, empezando siempre con un límite inferior.
- La carga completa de 3,3 V equivale aproximadamente a 0,65 A desde 12 V si el
  buck entrega 2 A con una eficiencia conservadora del 85 %. Falta medir ESP32,
  frontal y retroiluminación para validar F301 y la térmica.
- El esquema actual sigue siendo el subconjunto de baja tensión. La principal
  final integrará red, bomba, calentador y molino con aislamiento, protección y
  cortes independientes en la misma PCB.

## Telemetría de rails, 2026-09-19

- PA4/ADC2_IN17 mide `12V_PROTECTED` y PA5/ADC2_IN13 mide `24V_ACT_RAW`; ambas
  funciones se cotejaron con la tabla de pines LQFP64 del STM32G431.
- Cada entrada usa 200 kΩ sobre 10 kΩ y 100 nF: factor 21, 0,571 V nominal para
  12 V y 1,143 V nominal para 24 V. El rango teórico hasta 3,3 V alcanza 69,3 V,
  dejando margen de diagnóstico sin depender de los diodos internos del MCU.
- J114 expone GND, 3,3 V, ambos rails y ambas señales ADC para comparar firmware
  y multímetro. Es una cabecera de medida, no de alimentación.

## Colocación mecánica de conectores de la principal, 2026-09-19

- IMG_1098 se ajustó al contorno aceptado de 141,6 × 135,2 mm e IMG_1101 confirmó
  la entrada por el lateral izquierdo. J104/J108/J107/J113/J109/J105/J106 ocupan
  respectivamente las zonas originales de JP21/JP16/JP14/JP3/JP22/JP13/JP5,
  con incertidumbre fotográfica asignada de ±1,5 mm.
- `tools/layout_controller_pcb.py` consume esas coordenadas desde
  `mechanical-source.json`, asigna posición y orientación a las huellas y
  conserva MH1–MH3. El script también comprueba que los siete conectores no se
  desplacen al regenerar la PCB.
- JP8, JP24 y JP17 ya tienen huellas JST VH candidatas en sus posiciones
  originales. JP19, JP1 y JP9 conservan áreas temporales hasta identificar sus
  huellas. J110 queda junto a la zona del conector rojo.
- U201 queda junto al borde superior y la zona de exclusión de su antena está
  libre. El DRC detectó las invasiones de la primera iteración y la colocación
  final registrada pasa con 0 infracciones.
- El primer routing USB contiene 39 segmentos y 7 vías. Quedan 299 conexiones
  pendientes y tres avisos de paridad por los taladros mecánicos; no libera
  fabricación.

## Reglas de fabricación y routing de la principal, 2026-09-19

- Se evaluaron cuatro capas, pero la Rev A se mantiene en dos para reducir coste
  y plazo: F.Cu concentra señales/potencia y B.Cu se reserva como plano de GND
  casi continuo. El tamaño disponible y USB Full Speed hacen viable esta opción.
- `tools/configure_controller_rules.py` instala cinco clases: Default 0,20 mm,
  USB 0,20/0,20 mm, Power 0,50 mm, Switching 0,60 mm y Actuator 1,00 mm. Las
  vías aumentan de 0,60/0,30 a 1,00/0,50 mm según corriente.
- Se asignaron 26 redes explícitas. USB sigue como geometría provisional hasta
  elegir stack-up y recalcular 90 Ω en la herramienta del fabricante.
- Las áreas temporales de los seis conectores de potencia obligatorios y el keepout de antena
  de U201 se aplican a ambas capas de cobre.
- KiCad 10.0.6: DRC 0 infracciones, 299 conexiones abiertas y seis diferencias
  de paridad: MH1–MH3 y J116/J119/J120 sin huella. Las reglas preparan el routing,
  no liberan fabricación.

## Barrera red/SELV, distribución de red y ESP32-1U, 2026-09-19

- `configure_controller_rules.py` añade la clase `Mains` y escribe
  `controller-core-reva.kicad_dru`: 8 mm de separación y creepage entre red y
  SELV, y 2,5 mm entre pistas de redes de red distintas. Sobre la colocación
  anterior detectó 95 infracciones: fusibles junto al puente H, K701 en la zona
  lógica y J115 junto al buck de 12 V.
- Primer routing del STM32: anillo de VDD bajo el LQFP, una vía por VSS y
  desacoplo en cada par. El plano GND_UI de B.Cu se queda en el lado SELV.
- Fotos IMG_1098/1100/1101: el disipador original ocupa 40 × 33 mm en planta,
  mide 35 mm de alto, lleva dos TO-220 y está encima de JP8/JP19. El propietario
  midió 1,6 mm de espesor de placa y confirmó 35 mm de altura libre.
- U201 pasa a ESP32-S3-WROOM-1U-N8R8 (JLCPCB C2980300; 2.091 en stock y 1.984
  disponibles para pedido, observados hoy). Tiene el mismo pinout y libera la
  zona de exclusión de la antena, unos 1 990 mm².
- La placa se reorganiza con la distribución de la original. La barrera en L es
  una banda de 8 mm sin cobre, el hueco del disipador está reservado y PS701 está
  en vertical junto a J118. `sync_controller_pcb.py` admite ahora cambios de
  huella declarados.
- KiCad 10.0.6: ERC 0; netlist nativa 158 componentes / 528 pines coincidente.
  DRC con todas las severidades: 0 infracciones, 297 conexiones abiertas y seis
  diferencias de paridad (MH1–MH3 y J116/J119/J120 sin huella). No libera
  fabricación ni conexión a red.

## Entrada de red y salida de 24 V, 2026-09-19

- Rutadas la fase J118 → F701, la rama F702 → PS701, la fase protegida hacia
  RV701 y los dos pares de contactos de K701, y el neutro hacia PS701 y RV701.
  L_IN y PSU_L van anidados por el paso junto a PS701 y N cruza por B.Cu.
- Rutados PS701 → J121 y `24V_ACT_RAW` hasta J112, el buck de 12 V, F303, R704,
  J114, K701, D701 y F304. Retoques: F701/F702 intercambiados, J121 girado, y
  C307 y Q701 desplazados.
- KiCad 10.0.6, todas las severidades: 0 infracciones, incluidos 2,5 mm entre
  redes de red, 8 mm y creepage hasta SELV y la banda de barrera. Quedan 273
  conexiones abiertas; las redes de red y de 24 V están completas. Las fases
  van a 3 mm con 1 oz, anchura provisional hasta dimensionar el calentador.

- Decisión del propietario: cobre de 1 oz con las fases de carga duplicadas en
  las dos caras. L_IN hasta y = 77 mm, la fase protegida y el par NO de K701 van
  duplicados, con siete vías de 1,6/0,8 mm. DRC: 0 infracciones (152 segmentos,
  23 vías).
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

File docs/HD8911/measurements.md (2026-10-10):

# Registro de medidas

Medidas aportadas por el propietario. Cuando no se indicó instrumento, temperatura
o incertidumbre, se conserva expresamente como dato pendiente.

| ID | Fecha/operador | PCB | Conector/cavidad/orientación | Instrumento | Condiciones | Resultado/unidad | Evidencia | Revisión |
|---|---|---|---|---|---|---|---|---|
| MAIN-W | 2026-09-17 / foto | principal | borde izquierdo–derecho | calibre 0,05 mm | PCB desmontada, IMG_1098 | 141,6 ± 0,15 mm | [mecánica](main-board-mechanics.md) | Aceptada Rev A |
| MAIN-H | 2026-09-17 / foto | principal | borde superior–inferior | calibre 0,05 mm | PCB desmontada, IMG_1099 | 135,2 ± 0,15 mm | [mecánica](main-board-mechanics.md) | Aceptada Rev A |
| MAIN-MH | 2026-09-17 / fotogrametría | principal | 3 taladros, origen superior izquierdo | cuadrícula + contorno calibrado | vista casi normal, IMG_1098 | centros y diámetro en documento | [mecánica](main-board-mechanics.md) | Aceptada Rev A |
| LOAD-HEATER-R | 2026-09-20 / propietario | calentador | lengüetas 1 y 3 de JP19 | multímetro/modelo TBD | desconectado; temperatura TBD | 27,5 Ω | comunicación del propietario | Confirma 8,4 A a 230 V |
| LOAD-GRINDER-R | 2026-09-18 / propietario | molino | terminales del motor | multímetro/modelo TBD | desconectado; temperatura TBD | 68 Ω | comunicación del propietario | Medida inicial |
| LOAD-VALVE-R | 2026-09-18 / propietario | electroválvula | terminales de bobina | multímetro/modelo TBD | desconectada; temperatura TBD | 56,7 Ω | comunicación del propietario | Confirma ≈10 W a 24 V |
| LOAD-BU-R | 2026-09-18 / propietario | motor del grupo | rojo–azul de JP16 | multímetro/modelo TBD | desconectado; temperatura/posición de rotor TBD | 54,7 Ω | comunicación del propietario | Medida inicial |
| JP14-CONT | 2026-09-18 / propietario | puerta/cajón | dos blancos | continuidad/modelo TBD | puerta o cajón retirados | circuito abierto | comunicación del propietario | Estado funcional confirmado |
| JP14-CONT | 2026-09-18 / propietario | puerta/cajón | dos blancos | continuidad/modelo TBD | cajón y puerta colocados | circuito cerrado | comunicación del propietario | Estado funcional confirmado |
| JP5-PINOUT | 2026-09-18 / propietario | caudalímetro | vista cenital, pad cuadrado a la izquierda | seguimiento visual | unidad identificada 932-9521-B | 1 señal; 2 GND; 3 VCC | comunicación del propietario + hoja Digmesa | Pinout adoptado Rev A |
| JP22-PINOUT | 2026-09-18 / propietario | sensor de agua | arnés de tres hilos | seguimiento por color | módulo desconectado | rojo VCC; blanco señal; negro GND; VCC 3,3/5 V | comunicación del propietario + foto JP22 | Pinout adoptado Rev A; salida TBD |
| JP3-PINOUT | 2026-09-19 / propietario | electroválvula | vista cenital, pad cuadrado=pin 1 | seguimiento de continuidad y polaridad | arnés desconectado | JP3.1→solenoide.1=+24 V; JP3.2→solenoide.2=retorno 0 V; JP3.3–5 sin uso; terminal GND del solenoide sin conectar | comunicación del propietario | Pinout adoptado Rev A; supresión caracterizada en JP3-DIODE |
| JP3-DIODE | 2026-09-19 / propietario | OLAB 6000BH/B0DN | terminales 1–2, ambas polaridades | multímetro en modo diodo/modelo TBD | bobina desconectada | 0,073 V en ambos sentidos | comunicación del propietario | No se detecta diodo interno polarizado; rueda libre externa requerida |

Los ensayos con la máquina en marcha y con el prototipo están definidos en el
[plan de caracterización](characterization-plan.md); sus resultados se añaden a
esta tabla con el ID del plan.

Clasificar cada entrada como documento, observación, hipótesis o medida. Conservar
datos contradictorios y bloquear decisiones dependientes hasta resolverlos.

## Paquete de medidas prioritario para cerrar Rev A

Todas estas comprobaciones se hacen con la máquina desenchufada, los conectores
separados de la placa y ausencia de tensión verificada. No hace falta energizar la
máquina ni medir la red. Anotar siempre desde qué lado se mira el conector.

### 1. Fotos y conectores

Las fotos de cavidades con calibre de JP5, JP13, JP14, JP16 y JP22 ya están en
`photos/Conectores/`. La revisión con nonio del 2026-09-24 descartó XH y PH, y el
propietario identificó después JP3, JP5 y JP13 como HR A2506WV (ver
[photos.md](photos.md)). El 2026-10-10
identificó JP14 y JP16 (HR A2506WV-02P y -08P) y JP22 (JST ZH B3B-ZR); falta,
para todos, una comprobación real de acoplamiento con una muestra.

1. Frontal de cavidades, con la pestaña de retención visible.
2. Lateral de placa y carcasa, con calibre o regla en el mismo plano.

Registrar paso entre centros, ancho y alto de la carcasa, distancia desde el borde
de PCB, número de cavidades, cavidades vacías, orientación de pestaña y cualquier
logo o referencia moldeada. Añadir una foto legible del marcado del caudalímetro
para resolver `932-8521` frente a `932-9521` y fotos de ambas caras del módulo
capacitivo `421941306721`.

### 2. Continuidad de contactos

Usar continuidad u ohmios; registrar resistencia aproximada y estado mecánico:

| ID propuesto | Par | Estado A | Estado B | Resultado esperado del trabajo |
|---|---|---|---|---|
| JP14-CONT | dos blancos | puerta/cajón abierto | cerrado | **Cerrado únicamente con cajón y puerta colocados** |
| JP16-BRIDGE | dos negros | reposo | reposo | Confirmar puente local cercano a 0 Ω |
| JP16-PRES | dos verdes | grupo retirado | insertado | Determinar NO/NC funcional |
| JP16-WORK | dos rojos | fuera de posición | posición de trabajo | Determinar NO/NC funcional |

### 3. Resistencias de cargas desconectadas

Registrar resistencia en frío, temperatura ambiente y polaridad/colores usados:

| ID propuesto | Elemento | Par |
|---|---|---|
| LOAD-BU-R | motor del grupo `996530002796` | rojo–azul de JP16 |
| LOAD-VALVE-R | electroválvula `421944029371` | sus dos terminales |
| LOAD-GRINDER-R | molino `421944049151` | blanco–negro del motor desconectado |

Estas resistencias ayudan a detectar variantes y dimensionar el banco, pero no
sustituyen las corrientes de arranque y bloqueo. Ese ensayo se definirá después
con una fuente aislada y limitada; no se obtiene bloqueando motores desde la máquina.

### 4. Orden de conductores

JP5 ya queda identificado como 1 señal, 2 GND y 3 VCC. JP22 queda identificado
por color como rojo VCC, blanco señal y negro GND. Antes de fabricar todavía
conviene confirmar que la orientación de las huellas candidatas conserva ese
orden al enchufar los arneses. Para JP16, comprobar si la secuencia visual del manual coincide físicamente con
rojo motor, azul motor, negro, negro, verde, verde, rojo, rojo.

JP3 queda identificado: visto desde arriba, el pad cuadrado es el pin 1 y conduce
al pin 1 de la electroválvula, +24 V; JP3.2 conduce al pin 2, retorno de 0 V. Las
posiciones 3–5 no se usan y el terminal GND separado del solenoide no está conectado.
La bobina OLAB 6000BH/B0DN mide 0,073 V en modo diodo en ambos sentidos. La lectura
simétrica es compatible con la resistencia del devanado y no muestra una unión de
diodo interna polarizada. Se conserva la polaridad física y se requiere rueda libre externa.

## Plantilla para devolver resultados

| ID | Vista/orientación | Estado/condiciones | Medida | Foto asociada |
|---|---|---|---|---|
| JP14-CONT | dos blancos | puerta/cajón retirados | abierto | comunicación del propietario |
| JP14-CONT | dos blancos | cajón y puerta colocados | cerrado | comunicación del propietario |
| JP16-BRIDGE | pestaña arriba | desconectado |  |  |
| JP16-PRES | pestaña arriba | grupo retirado/insertado |  |  |
| JP16-WORK | pestaña arriba | fuera/en trabajo |  |  |
| LOAD-BU-R | rojo–azul | desconectado; temperatura TBD | 54,7 Ω | comunicación del propietario |
| LOAD-VALVE-R | terminales bobina | desconectada; temperatura TBD | 56,7 Ω | comunicación del propietario |
| JP3-DIODE | terminales bobina, ambas polaridades | desconectada | 0,073 V / 0,073 V | comunicación del propietario |
| LOAD-GRINDER-R | blanco–negro | desconectado; temperatura TBD | 68 Ω | comunicación del propietario |

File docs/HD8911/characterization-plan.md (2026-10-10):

# Plan de caracterización de la HD8911

Estado: propuesta del 2026-09-23. Ningún ensayo está hecho. Los resultados se
registran en el [registro de medidas](measurements.md) con el ID de este plan.

La Rev A se diseña hoy con valores supuestos o derivados, y la primera tanda de
prototipos tiene que convertirlos en medidas. El caso más claro es el molinillo:
la etapa se dimensiona a **3 A**, casi la corriente de bloqueo, en vez de
suponer una corriente de marcha (ver
[etapa del molinillo](../../hardware/power/power-architecture.md#etapa-del-molinillo)).
Este plan reúne los ensayos iniciales que caracterizan la cafetera, qué decisión
desbloquea cada uno y con qué criterio se da por bueno el valor supuesto.

## Reglas comunes

- Cada resultado lleva fecha, operador, instrumento con modelo, temperatura
  ambiente y el estado de la máquina, como en el registro actual. Un valor sin
  instrumento se guarda como observación, no como medida.
- Los ensayos se agrupan por nivel de riesgo:
  - **N0**: máquina desenchufada y sin tensión comprobada.
  - **N1**: solo SELV, con fuente de banco aislada y limitada en corriente.
  - **N2**: máquina conectada a red con su placa original o con el prototipo.
    Los hace una persona cualificada, con un procedimiento aparte revisado y
    solo con instrumentos aislados y sin contacto: pinza amperimétrica, sonda
    diferencial homologada para la categoría, termopar fijado antes de conectar.
    Nunca se abre la máquina ni se toca el cableado con tensión.
- Este documento dice qué medir y para qué. No es un procedimiento de trabajo
  bajo tensión, igual que el resto de la documentación
  ([safety.md](../safety.md)).
- Siempre que se pueda, se mide primero con la **placa original**. Así se
  obtiene la referencia de la máquina sana antes de introducir el prototipo, y
  el prototipo se valida después contra ella.
- No se bloquean motores ni se deja el calentador sin agua para medir el peor
  caso. Las corrientes de bloqueo se calculan con la resistencia del devanado.

## Prioridad

| Prioridad | Qué desbloquea | Ensayos |
|---|---|---|
| A | Cerrar la PCB Rev A: corrientes, térmica, fuente y emisión conducida | GR-01 a GR-06, BU-01 a BU-04, VA-01 a VA-03, PU-01 a PU-03, PS-01, PS-02, TH-01, EM-01, EM-02 |
| B | Límites y calibraciones del firmware | HT, NT, FL, WL, SW, resto de GR, BU y PU |
| C | Reproducir el comportamiento de la original | OR-01 a OR-08 |

## Molinillo (JP8)

Dimensionado de diseño: 3 A. Bloqueo y arranque derivados: 3,4 A eficaces con
68 Ω. Fusible, triac, pistas y reparto con el calentador valen para cualquier
marcha medida. Solo el puente depende de la medida: si GR-03 no pasa de 1,5 A en
ningún ajuste de molido y GR-06 deja el puente por debajo de 100 °C, el KBP410
se queda. Si no, se cambia a cuatro diodos discretos.
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

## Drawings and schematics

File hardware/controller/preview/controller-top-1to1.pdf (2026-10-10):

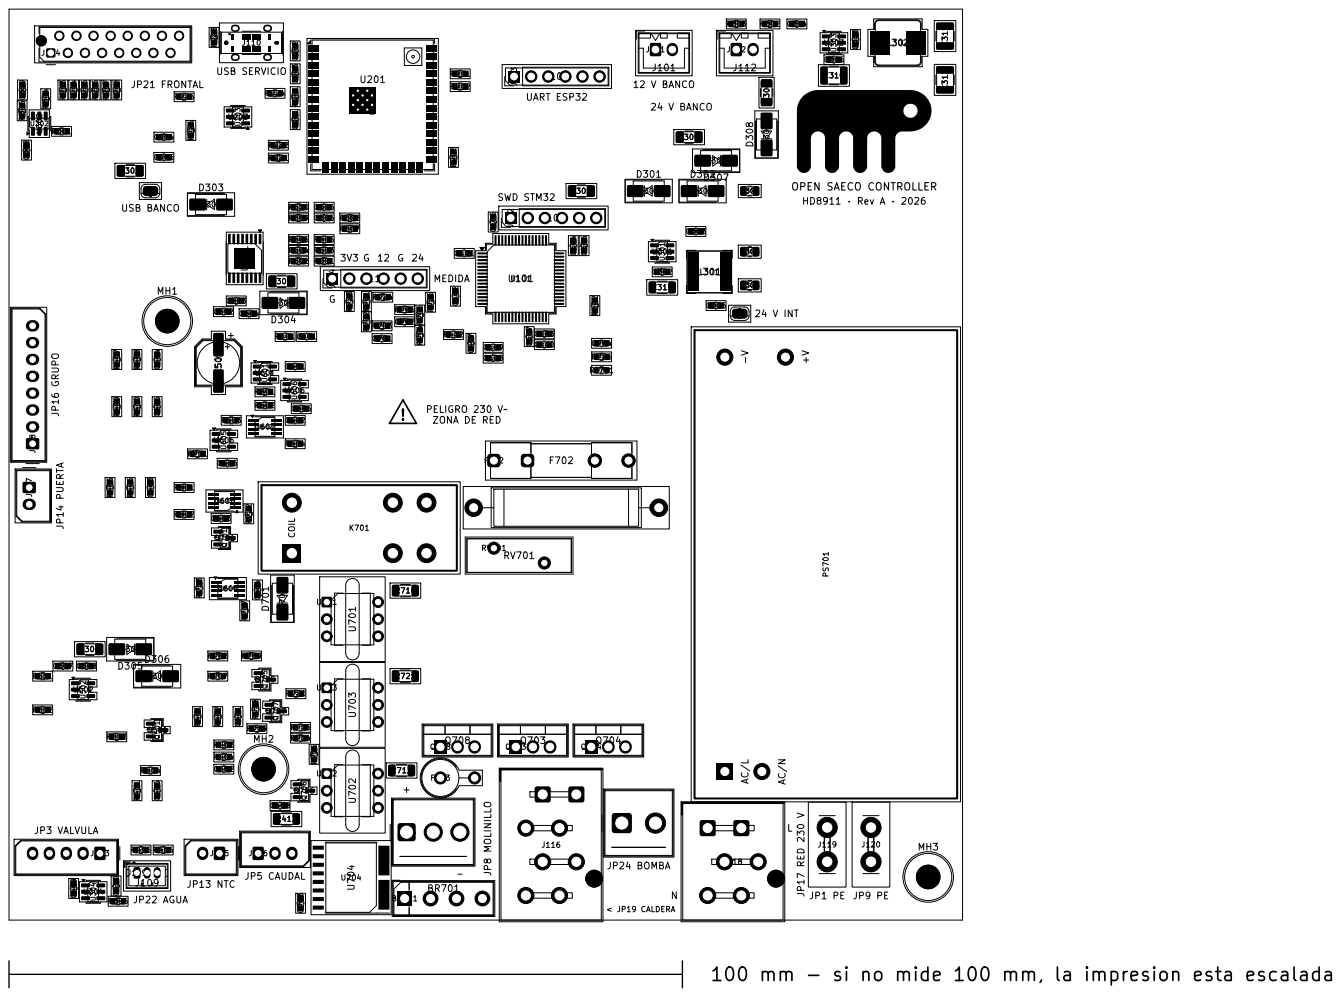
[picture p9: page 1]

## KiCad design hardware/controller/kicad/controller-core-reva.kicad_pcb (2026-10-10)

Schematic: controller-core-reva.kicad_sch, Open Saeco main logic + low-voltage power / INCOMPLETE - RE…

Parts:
BR701: KBP410 / grinder bridge; Diode_Bridge_Vishay_KBPM; mpn KBP410; lcsc C840747
C101: 100nF; C_0603_1608Metric; mpn CC0603KRX7R9BB104; lcsc C14663
C102: 100nF / VDD16; C_0603_1608Metric; mpn CC0603KRX7R9BB104; lcsc C14663
C103: 100nF / VDD32; C_0603_1608Metric; mpn CC0603KRX7R9BB104; lcsc C14663
C104: 100nF / VDD48; C_0603_1608Metric; mpn CC0603KRX7R9BB104; lcsc C14663
C105: 100nF / VDD64; C_0603_1608Metric; mpn CC0603KRX7R9BB104; lcsc C14663
C106: 4.7uF / bulk STM; C_0603_1608Metric; mpn CL10A475KO8NNNC; lcsc C19666
C107: 10nF / VDDA29; C_0603_1608Metric; mpn 0603B103K500NT; lcsc C57112
C108: 1uF / VDDA29; C_0603_1608Metric; mpn CL10A105KB8NNNC; lcsc C15849
C109: 100nF / VREF28; C_0603_1608Metric; mpn CC0603KRX7R9BB104; lcsc C14663
C110: 1uF / VREF28; C_0603_1608Metric; mpn CL10A105KB8NNNC; lcsc C15849
C111: 100nF / VBAT1; C_0603_1608Metric; mpn CC0603KRX7R9BB104; lcsc C14663
C201: 1uF; C_0603_1608Metric; mpn CL10A105KB8NNNC; lcsc C15849
C202: 100nF / ESP pad2; C_0603_1608Metric; mpn CC0603KRX7R9BB104; lcsc C14663
C203: 10uF / ESP pad2; C_0603_1608Metric; mpn CL10A106MA8NRNC; lcsc C96446
C204: 10nF / VBUS sense; C_0603_1608Metric; mpn 0603B103K500NT; lcsc C57112
C205: 1uF / USB VBUS; C_0603_1608Metric; mpn CL10A105KB8NNNC; lcsc C15849
C301: 10uF / 25V input; C_0805_2012Metric; mpn CL21A106KAYNNNE; lcsc C15850
C302: 100nF / input HF; C_0603_1608Metric; mpn CC0603KRX7R9BB104; lcsc C14663
C303: 100nF / bootstrap; C_0603_1608Metric; mpn CC0603KRX7R9BB104; lcsc C14663
C304, C305: 22uF / 10V output; C_0805_2012Metric; mpn TCC0805X5R226M100FT; lcsc C380338
C306: 100nF / output HF; C_0603_1608Metric; mpn CC0603KRX7R9BB104; lcsc C14663
C308: 1uF / switch input; C_0603_1608Metric; mpn CL10A105KB8NNNC; lcsc C15849
C309: 10uF / switch output; C_0603_1608Metric; mpn CL10A106MA8NRNC; lcsc C96446
C310: 10uF / 50V input 1210; C_1210_3225Metric; mpn CL32B106KBJNNNE; lcsc C138687
C311: 22uF / 25V output A; C_1210_3225Metric; mpn TCC1210X7R226K250MT; lcsc C49118556
C312: 22uF / 25V output B; C_1210_3225Metric; mpn TCC1210X7R226K250MT; lcsc C49118556
C313: 100nF / BST; C_0603_1608Metric; mpn CC0603KRX7R9BB104; lcsc C14663
C314: 56pF / feed-forward; C_0603_1608Metric; mpn 0603C0G560J500NT; lcsc C49326334
C315: 10uF / 50V U301 VIN; C_1206_3216Metric; mpn CL31B106KBHNNNE; lcsc C89632
C316: 100nF / U303 VIN HF; C_0603_1608Metric; mpn CC0603KRX7R9BB104; lcsc C14663
C401: 100nF / NTC filtro; C_0603_1608Metric; mpn CC0603KRX7R9BB104; lcsc C14663
C402: 10nF / FLOW filtro; C_0603_1608Metric; mpn 0603B103K500NT; lcsc C57112
C403: 100nF / DOOR filtro; C_0603_1608Metric; mpn CC0603KRX7R9BB104; lcsc C14663
C404: 100nF / PRES filtro; C_0603_1608Metric; mpn CC0603KRX7R9BB104; lcsc C14663
C405: 100nF / WORK filtro; C_0603_1608Metric; mpn CC0603KRX7R9BB104; lcsc C14663
C406: 10nF / WATER filtro; C_0603_1608Metric; mpn 0603B103K500NT; lcsc C57112
C407: 100nF / GRINDER I filtro; C_0603_1608Metric; mpn CC0603KRX7R9BB104; lcsc C14663
C408: 100nF / FLOW VCC; C_0603_1608Metric; mpn CC0603KRX7R9BB104; lcsc C14663
C409: 100nF / JP22 switch input; C_0603_1608Metric; mpn CC0603KRX7R9BB104; lcsc C14663
C410: 1uF / JP22 VCC; C_0603_1608Metric; mpn CL10A105KB8NNNC; lcsc C15849
C501: 100uF / 35V motor bulk; CP_Elec_6.3x7.7; mpn VZH101M1VTR-0607; lcsc C176683
C502: 100nF / VM local; C_0603_1608Metric; mpn CC0603KRX7R9BB104; lcsc C14663
C503: 100nF / VCP-VM; C_0603_1608Metric; mpn CC0603KRX7R9BB104; lcsc C14663
C504: 22nF / CPH-CPL; C_0603_1608Metric; mpn 0603B223K500NT; lcsc C77571
C505: 100nF / VREF; C_0603_1608Metric; mpn CC0603KRX7R9BB104; lcsc C14663
C506: 10nF / IPROPI; C_0603_1608Metric; mpn 0603B103K500NT; lcsc C57112
C507: 100nF / driver local; C_0603_1608Metric; mpn CC0603KRX7R9BB104; lcsc C14663
C508: 1uF / driver local; C_0603_1608Metric; mpn CL10A105KB8NNNC; lcsc C15849
C601: 100nF / supervisor local; C_0603_1608Metric; mpn CC0603KRX7R9BB104; lcsc C14663
C602: 100nF / logic local; C_0603_1608Metric; mpn CC0603KRX7R9BB104; lcsc C14663
C603: 100nF / arm gate local; C_0603_1608Metric; mpn CC0603KRX7R9BB104; lcsc C14663
C604: 100nF / pump gate local; C_0603_1608Metric; mpn CC0603KRX7R9BB104; lcsc C14663
C605: 100nF / reset buffer local; C_0603_1608Metric; mpn CC0603KRX7R9BB104; lcsc C14663
C606: 100nF / WDI gate local; C_0603_1608Metric; mpn CC0603KRX7R9BB104; lcsc C14663
C701: 100nF / 12V ADC; C_0603_1608Metric; mpn CC0603KRX7R9BB104; lcsc C14663
C702: 100nF / 24V ADC; C_0603_1608Metric; mpn CC0603KRX7R9BB104; lcsc C14663
C703: 100nF / U704 VS; C_0603_1608Metric; mpn CC0603KRX7R9BB104; lcsc C14663
C704: 100nF / heatsink NTC; C_0603_1608Metric; mpn CC0603KRX7R9BB104; lcsc C14663
C705: RC snubber C / Q704, DNP until PU-03; C_1812_4532Metric; not fitted
C706: RC snubber C / Q708, DNP until GR-05; C_1812_4532Metric; not fitted
C707: 56nF X2 / mains input; C_2220_5750Metric; mpn GA355XR7GB563KW06L; lcsc C161105
C708: Motor suppression C / JP8, DNP until EMI test; C_2220_5750Metric; not fitted
D301, D304, D305: SS34; D_SMA; mpn SS34; lcsc C2909963
D302: SMAJ15A; D_SMA; mpn SMAJ15A; lcsc C148216
D303: SS34 / USB power OR; D_SMA; mpn SS34; lcsc C2909963
D306: SS34 / flyback; D_SMA; mpn SS34; lcsc C2909963
D307: SS34 / bench OR; D_SMA; mpn SS34; lcsc C2909963
D308: SS34 / bench polarity; D_SMA; mpn SS34; lcsc C2909963
D701: SS34 / relay flyback; D_SMA; mpn SS34; lcsc C2909963
F301, F303, F304: 1A / 72VDC; Fuse_1206_3216Metric; mpn 1206TD-1A; lcsc C2838907
F302: 500mA resettable PTC; Fuse_1206_3216Metric; mpn 1206L050YR; lcsc C163512
F305: 1A / 72VDC bench; Fuse_1206_3216Metric; mpn 1206TD-1A; lcsc C2838907
F306: 2A / 72VDC bench; Fuse_1206_3216Metric; mpn 1206TD-2A; lcsc C2838912
F701: T12AH / 250V MAIN; Fuse_Littelfuse_0215_5x20mm_Axial_Horizontal_P27.50mm; mpn 0215012.MXEP; lcsc C142789
F702: T2AH / PSU; Fuseholder_Clip-5x20mm_Littelfuse_111_Inline_P20.00x5.00mm_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; mpn 0215002.MXP; lcsc C142716
F703: T4AH / 250V grinder; Fuse_Littelfuse_0215_5x20mm_Axial_Vertical_P5.08mm; mpn 0215004.MXEP; lcsc C178840
J101: 12V_ISOLATED_INPUT / JST XH; JST_XH_B2B-XH-A_1x02_P2.50mm_Vertical; mpn B2B-XH-A(LF)(SN); lcsc C158012
J102: STM_SWD / 1x6 2.54mm; PinHeader_1x06_P2.54mm_Vertical; mpn HX PH254-01-06-Z-L11.5 through hole hea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; lcsc C52016393
J103: ESP_UART / 1x6 2.54mm; PinHeader_1x06_P2.54mm_Vertical; mpn HX PH254-01-06-Z-L11.5 through hole hea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; lcsc C52016393
J104: UI_LINK / WR-MM 16; Wurth_WR-MM_690367181672_2x08_P1.27mm_Vertical; mpn 690367181672; lcsc C19103863
J105: JP13 NTC / 2 vías; HR_A2506WV-02P_1x02_P2.50mm_Vertical; mpn A2506WV-02P; lcsc C382532
J106: JP5 FLOW ADAPTER / VCC-GND-OC; HR_A2506WV-03P_1x03_P2.50mm_Vertical; mpn A2506WV-03P; lcsc C382533
J107: JP14 DOOR / A2506WV-02P; HR_A2506WV-02P_1x02_P2.50mm_Vertical; mpn A2506WV-02P; lcsc C382532
J108: JP16 VISUAL V8..V1 / A2506WV-08P; HR_A2506WV-08P_1x08_P2.50mm_Vertical; mpn A2506WV-08P; lcsc C476906
J109: JP22 WATER / RED-WHITE-BLACK; JST_ZH_B3B-ZR_1x03_P1.50mm_Vertical; mpn B3B-ZR(LF)(SN); lcsc C158001
J110: USB-C SERVICE / USB 2.0; USB_C_Receptacle_HRO_TYPE-C-31-D-06_Vertical; mpn TYPE-C-31-D-06; lcsc C2689964
J111: USB BENCH POWER / OPEN; SolderJumper-2_P1.3mm_Open_RoundedPad1.0x1.5mm
J112: 24V_ACTUATOR_INPUT / JST XH; JST_XH_B2B-XH-A_1x02_P2.50mm_Vertical; mpn B2B-XH-A(LF)(SN); lcsc C158012
J113: JP3 VALVE / A2506; HR_A2506WV-05P_1x05_P2.50mm_Vertical; mpn A2506WV-05P; lcsc C382535
J114: POWER PROBE / MEASURE ONLY; PinHeader_1x06_P2.54mm_Vertical; mpn HX PH254-01-06-Z-L11.5 through hole hea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; lcsc C52016393
J115: JP8 GRINDER / 320VDC; LEOCO_3941P03_1x03_P3.96mm_Vertical; mpn 3941P03*000
J116: JP19 HEATER / 1900W 27R5; TE_RAST5_1971845-4_1x04_P5.00mm_Vertical; mpn 1971845-4; lcsc C2149727
J117: JP24 PUMP / 230VAC; LEOCO_5001P02_1x02_P5.00mm_Vertical; mpn 5001P020013
J118: JP17 MAINS / L-N; TE_RAST5_1971845-3_1x03_P5.00mm_Vertical; mpn 1971845-3; lcsc C5169636
J119: JP1 PE TO BOILER; TE_FASTON_63824-1_Tab_6.35mm_Vertical; mpn 63824-1; lcsc C575074
J120: JP9 PE INPUT; TE_FASTON_63824-1_Tab_6.35mm_Vertical; mpn 63824-1; lcsc C575074
J121: 24V INTERNAL SELECT / OPEN FOR BENCH; SolderJumper-2_P1.3mm_Bridged_RoundedPad1.0x1.5mm
K701: G5RL-1A-E-HR DC24; Relay_SPST_Omron_G5RL-1A-E-TV8; mpn G5RL-1A-E-HR DC24; lcsc C397236
L301: 3.9uH; L_Bourns-SRN6028; mpn SRN6028C-3R9M; lcsc C19947652
L302: 10uH / 3.5A; L_Bourns_SRP7028A_7.3x6.6mm; mpn SRP7028A-100M; lcsc C2687402
PS701: IRM-30-24; MeanWell_IRM-30_THT; mpn IRM-30-24; lcsc C6280124
Q501: SI2308A; SOT-23; mpn SI2308A; lcsc C347491
Q701: BSS138LT1G / relay coil; SOT-23; mpn BSS138LT1G; lcsc C82045
Q703: BTA24-800BWRG / heater; TO-220-3_Vertical; mpn BTA24-800BWRG; lcsc C15293
Q704: BTA24-800BWRG / pump; TO-220-3_Vertical; mpn BTA24-800BWRG; lcsc C15293
Q705: BSS138LT1G / heater opto LED; SOT-23; mpn BSS138LT1G; lcsc C82045
Q706: BSS138LT1G / pump opto LED; SOT-23; mpn BSS138LT1G; lcsc C82045
Q707: BSS138LT1G / grinder opto LED; SOT-23; mpn BSS138LT1G; lcsc C82045
Q708: BTA24-800BWRG / grinder; TO-220-3_Vertical; mpn BTA24-800BWRG; lcsc C15293
R101, R102, R201, R202: 10k; R_0603_1608Metric; mpn 0603WAF1002T5E; lcsc C25804
R211, R212, R213, R214, R215, R216, R217, R218, R221, R222: 33; R_0603_1608Metric; mpn 0603WAF330JT5E; lcsc C23140
R223: 5.1k / CC1 Rd; R_0603_1608Metric; mpn 0603WAF5101T5E; lcsc C23186
R224: 5.1k / CC2 Rd; R_0603_1608Metric; mpn 0603WAF5101T5E; lcsc C23186
R225: 100k / VBUS sense top; R_0603_1608Metric; mpn 0603WAF1003T5E; lcsc C25803
R226: 100k / VBUS sense bottom; R_0603_1608Metric; mpn 0603WAF1003T5E; lcsc C25803
R301: 100k; R_0603_1608Metric; mpn 0603WAF1003T5E; lcsc C25803
R302: 330k / 12V FB high; R_0603_1608Metric; mpn 0603WAF3303T5E; lcsc C23137
R303: 24k / 12V FB low; R_0603_1608Metric; mpn 0603WAF2402T5E; lcsc C23352
R304: 49.9k / UI ILIM 0.5A; R_0603_1608Metric; mpn 0603WAF4992T5E; lcsc C23184
R305: 1k / UI discharge; R_0603_1608Metric; mpn 0603WAF1001T5E; lcsc C21190
R306: 210k / JP22 ILIM 0.13A; R_0603_1608Metric; mpn 0603WAF2103T5E; lcsc C22952
R401: 4.7k / NTC pull-up; R_0603_1608Metric; mpn 0603WAF4701T5E; lcsc C23162
R402: 1k / NTC serie; R_0603_1608Metric; mpn 0603WAF1001T5E; lcsc C21190
R403: 4.7k / FLOW pull-up; R_0603_1608Metric; mpn 0603WAF4701T5E; lcsc C23162
R404: 1k / FLOW serie; R_0603_1608Metric; mpn 0603WAF1001T5E; lcsc C21190
R405: 10k / DOOR pull-up; R_0603_1608Metric; mpn 0603WAF1002T5E; lcsc C25804
R406: 1k / DOOR serie; R_0603_1608Metric; mpn 0603WAF1001T5E; lcsc C21190
R407: 10k / PRES pull-up; R_0603_1608Metric; mpn 0603WAF1002T5E; lcsc C25804
R408: 1k / PRES serie; R_0603_1608Metric; mpn 0603WAF1001T5E; lcsc C21190
R409: 10k / WORK pull-up; R_0603_1608Metric; mpn 0603WAF1002T5E; lcsc C25804
R410: 1k / WORK serie; R_0603_1608Metric; mpn 0603WAF1001T5E; lcsc C21190
R411: 1k / WATER serie; R_0603_1608Metric; mpn 0603WAF1001T5E; lcsc C21190
R412: 1k / GRINDER I serie; R_0603_1608Metric; mpn 0603WAF1001T5E; lcsc C21190
R413: 390 / FLOW VCC limit; R_1206_3216Metric; mpn ERJ-P08J391V; lcsc C2086379
R415: 100k / WATER pull-up DNP; R_0603_1608Metric; mpn 0603WAF1003T5E; lcsc C25803; not fitted
R416: 100k / WATER pull-down DNP; R_0603_1608Metric; mpn 0603WAF1003T5E; lcsc C25803; not fitted
R501: 33 / EN; R_0603_1608Metric; mpn 0603WAF330JT5E; lcsc C23140
R502: 10k / EN pull-down; R_0603_1608Metric; mpn 0603WAF1002T5E; lcsc C25804
R503: 33 / PH; R_0603_1608Metric; mpn 0603WAF330JT5E; lcsc C23140
R504: 10k / PH pull-down; R_0603_1608Metric; mpn 0603WAF1002T5E; lcsc C25804
R505: 33 / nSLEEP; R_0603_1608Metric; mpn 0603WAF330JT5E; lcsc C23140
R506: 10k / nSLEEP pull-down; R_0603_1608Metric; mpn 0603WAF1002T5E; lcsc C25804
R507: 10k / nFAULT pull-up; R_0603_1608Metric; mpn 0603WAF1002T5E; lcsc C25804
R508: 18k / VREF top; R_0603_1608Metric; mpn 0603WAF1802T5E; lcsc C25810
R509: 49.9k / VREF bottom; R_0603_1608Metric; mpn 0603WAF4992T5E; lcsc C23184
R510: 2.4k / IPROPI; R_0603_1608Metric; mpn 0603WAF2401T5E; lcsc C22940
R511: 33 / IN; R_0603_1608Metric; mpn 0603WAF330JT5E; lcsc C23140
R512: 10k / IN pull-down; R_0603_1608Metric; mpn 0603WAF1002T5E; lcsc C25804
R513: 33 / gate; R_0603_1608Metric; mpn 0603WAF330JT5E; lcsc C23140
R514: 100k / gate pull-down; R_0603_1608Metric; mpn 0603WAF1003T5E; lcsc C25803
R601: 33 / WDI; R_0603_1608Metric; mpn 0603WAF330JT5E; lcsc C23140
R602: 1k / kick pull-down; R_0603_1608Metric; mpn 0603WAF1001T5E; lcsc C21190
R603: 10k / brew arm pull-down; R_0603_1608Metric; mpn 0603WAF1002T5E; lcsc C25804
R604: 10k / valve pull-down; R_0603_1608Metric; mpn 0603WAF1002T5E; lcsc C25804
R701: 100k / 12V div A; R_0603_1608Metric; mpn 0603WAF1003T5E; lcsc C25803
R702: 100k / 12V div B; R_0603_1608Metric; mpn 0603WAF1003T5E; lcsc C25803
R703: 10k / 12V div low; R_0603_1608Metric; mpn 0603WAF1002T5E; lcsc C25804
R704: 100k / 24V div A; R_0603_1608Metric; mpn 0603WAF1003T5E; lcsc C25803
R705: 100k / 24V div B; R_0603_1608Metric; mpn 0603WAF1003T5E; lcsc C25803
R706: 10k / 24V div low; R_0603_1608Metric; mpn 0603WAF1002T5E; lcsc C25804
R707, R714, R718: 33 / opto LED gate; R_0603_1608Metric; mpn 0603WAF330JT5E; lcsc C23140
R708, R715, R719: 100k / opto LED off; R_0603_1608Metric; mpn 0603WAF1003T5E; lcsc C25803
R709, R716, R720: 1k / opto LED series; R_0603_1608Metric; mpn ESR03EZPF1001; lcsc C2653986
R710, R712, R721: 390 / gate limit 500V; R_1206_3216Metric; mpn ERJ-P08J391V; lcsc C2086379
R711: 10k / heater arm pull-down; R_0603_1608Metric; mpn 0603WAF1002T5E; lcsc C25804
R713: 10k / pump arm pull-down; R_0603_1608Metric; mpn 0603WAF1002T5E; lcsc C25804
R717: 10k / grinder arm pull-down; R_0603_1608Metric; mpn 0603WAF1002T5E; lcsc C25804
R722: 10k / mains arm pull-down; R_0603_1608Metric; mpn 0603WAF1002T5E; lcsc C25804
R723: 10k / J114 3V3 probe; R_0603_1608Metric; mpn 0603WAF1002T5E; lcsc C25804
R724: 10k / J114 12V probe; R_0603_1608Metric; mpn 0603WAF1002T5E; lcsc C25804
R725: 10k / J114 24V probe; R_0603_1608Metric; mpn 0603WAF1002T5E; lcsc C25804
R726: 10k / heatsink NTC pull-up; R_0603_1608Metric; mpn 0603WAF1002T5E; lcsc C25804
R727: RC snubber R / Q704, DNP until PU-03; R_2512_6332Metric; not fitted
R728: RC snubber R / Q708, DNP until GR-05; R_2512_6332Metric; not fitted
R801: 33 / relay gate; R_0603_1608Metric; mpn 0603WAF330JT5E; lcsc C23140
R802: 100k / relay off; R_0603_1608Metric; mpn 0603WAF1003T5E; lcsc C25803
RT701: 10k B3380 / heatsink air; R_0603_1608Metric; mpn NCP18XH103F03RB; lcsc C13564
RV701: S14K275 / 275VAC MOV; RV_Disc_D15.5mm_W5mm_P7.5mm; mpn B72214S0271K101; lcsc C7502584
U101: STM32G431RBT6; LQFP-64_10x10mm_P0.5mm; mpn STM32G431RBT6; lcsc C431633
U201: ESP32-S3-WROOM-1U-N8R8; ESP32-S3-WROOM-1U; mpn ESP32-S3-WROOM-1U-N8R8; lcsc C2980300
U203: USBLC6-2SC6; SOT-23-6; mpn USBLC6-2SC6; lcsc C7519
U301: AP63203WU-7; TSOT-23-6; mpn AP63203WU-7; lcsc C780769
U302: TPS2553DBVR / UI 0.5A limit; SOT-23-6; mpn TPS2553DBVR; lcsc C55266
U303: AP63301WU-7 / 24V to 12V; TSOT-23-6; mpn AP63301WU-7; lcsc C2158003
U304: TPS2553DBVR / JP22 0.13A limit; SOT-23-6; mpn TPS2553DBVR; lcsc C55266
U501: DRV8876PWPR; HTSSOP-16-1EP_4.4x5mm_P0.65mm_EP3x3mm; mpn DRV8876PWPR; lcsc C575551
U502: UCC27517DBVR; SOT-23-5; mpn UCC27517DBVR; lcsc C99395
U601: TPS3828-33DBVR; SOT-23-5; mpn TPS3828-33DBVR; lcsc C20032
U602, U603, U604: SN74LVC2G08DCTR; SSOP-8_2.95x2.8mm_P0.65mm; mpn SN74LVC2G08DCTR; lcsc C352973
U605: SN74LVC1G17DBVR; SOT-23-5; mpn SN74LVC1G17DBVR; lcsc C7836
U606: SN74LVC1G132DBVR; SOT-23-5; mpn SN74LVC1G132DBVR; lcsc C403723
U701, U702, U703: MOC3083 / zero-cross; DIP-6_W7.62mm_BarrierSlot; mpn MOC3083; lcsc C10797
U704: TMCS1133B4AQDVGR / grinder current; TI_DVG0010A_SOIC-10W_HV; mpn TMCS1133B4AQDVGR; lcsc C36873216

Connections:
/3V3_CORE: C102.1, C103.1, C104.1, C105.1, C106.1, C107.1, C108.1, C109.1, C110.1, C111.1, C202.1, C203.1, C304.1, C305.1, C306.1, C308.1, C409.1, C601.1, C602.1, C603.1, C604.1, C605.1, C606.1, C703.1, J102.1, J103.1, L301.2, R101.1, R201.1, R202.1, R301.1, R401.1, R403.1, R405.1, R407.1, R409.1, R507.1, R508.1, R723.1, R726.1, U101.1 (VBAT), U101.16 (VDD), U101.28 (VREF+), U101.29 (VDDA), U101.32 (VDD), U101.48 (VDD), U101.64 (VDD), U201.2 (3V3), U301.1 (FB), U302.1 (IN), U304.1 (IN), U304.3 (EN), U601.3 (~MR), U601.5 (VDD), U602.8 (VCC), U603.8 (VCC), U604.8 (VCC), U605.5 (VCC), U606.5 (VCC), U704.8 (VOC), U704.9 (VS), U704.10 (VS)
/3V3_UI: C309.1, J104.1, R305.1, U302.6 (OUT)
/12V_BENCH_FUSED: D307.2 (A), F305.2
/12V_BENCH_RAW: F305.1, J101.1
/12V_FUSED: D301.2 (A), F301.2
/12V_ISO_RAW: C311.1, C312.1, C314.1, F301.1, L302.2, R302.1
/12V_PROTECTED: C301.1, C302.1, C315.1, C507.1, C508.1, D301.1 (K), D302.1 (K), D303.1 (K), D307.1 (K), R413.1, R701.1, R709.1, R716.1, R720.1, R724.1, U301.2 (EN), U301.3 (VIN), U502.1 (VDD)
/24V_ACT_RAW: C310.1, C316.1, D308.1 (K), D701.1 (K), F303.1, F304.1, J121.2, K701.1 (COIL_A), R704.1, R725.1, U303.2 (EN), U303.3 (VIN)
/24V_BENCH_FUSED: D308.2 (A), F306.2
/24V_BENCH_RAW: F306.1, J112.1
/24V_BREW: C501.1, C502.1, C503.2, D304.1 (K), U501.11 (VM)
/24V_BREW_FUSED: D304.2 (A), F303.2
/24V_INTERNAL_RAW: J121.1, PS701.4 (+V)
/24V_VALVE: D305.1 (K), D306.1 (K), J113.5
/24V_VALVE_FUSED: D305.2 (A), F304.2
/BL_RAW: R218.1, U201.7 (IO7)
/BREW_CPH: C504.1, U501.13 (CPH)
/BREW_CPL: C504.2, U501.14 (CPL)
/BREW_CURRENT_ADC: C506.1, R510.1, U101.8 (PC0), U501.6 (IPROPI)
/BREW_DIR_DRV: R503.2, R504.1, U501.2 (PH/IN2)
/BREW_DIR_RAW: R503.1, U101.3 (PC14)
/BREW_EN_DRV: R501.2, R502.1, U501.1 (EN/IN1)
/BREW_FAULT_N: R507.2, U101.59 (PB6), U501.4 (nFAULT)
/BREW_OUT1: J108.8, U501.8 (OUT1)
/BREW_OUT2: J108.7, U501.10 (OUT2)
/BREW_PWM_RAW: R501.1, U101.5 (PF0)
/BREW_SLEEP_DRV: R505.2, R506.1, U501.3 (nSLEEP)
/BREW_SLEEP_INTERLOCK: R505.1, U602.7 (1Y)
/BREW_SLEEP_RAW: R603.1, U101.58 (PB5), U602.1 (1A)
/BREW_VCP: C503.1, U501.12 (VCP)
/BREW_VREF: C505.1, R508.2, R509.1, U501.5 (VREF)
/BST_NODE: C303.1, U301.6 (BST)
/BUCK12_BST: C313.1, U303.6 (BST)
/BUCK12_FB: C314.2, R302.2, R303.1, U303.1 (FB)
/BUCK12_SW: C313.2, L302.1, U303.5 (SW)
/BU_BRIDGE: J108.5, J108.6
/BU_PRESENT_N: C404.1, R408.2, U101.10 (PC2)
/BU_PRESENT_RAW: J108.4, R407.2, R408.1
/BU_WORK_N: C405.1, R410.2, U101.12 (PA0)
/BU_WORK_RAW: J108.2, R409.2, R410.1
/CS_RAW: R215.1, U201.18 (IO10)
/DC_RAW: R216.1, U201.17 (IO9)
/DOOR_CLOSED_N: C403.1, R406.2, U101.13 (PA1)
/DOOR_RAW: J107.2, R405.2, R406.1
/ESP_BOOT0: J103.6, R202.2, U201.27 (IO0)
/ESP_DEBUG_RX: J103.4, U201.36 (RXD0)
/ESP_DEBUG_TX: J103.3, U201.37 (TXD0)
/ESP_EN: C201.1, J103.5, R201.2, U201.3 (EN)
/ESP_TO_STM: R212.2, U101.44 (PA10)
/ESP_TX_RAW: R212.1, U201.35 (IO42)
/FLOW_RAW: J106.1, R403.2, R404.1
/FLOW_TIM: C402.1, R404.2, U101.14 (PA2)
/FLOW_VCC: C408.1, J106.3, R413.2
/GND_UI: C101.2, C102.2, C103.2, C104.2, C105.2, C106.2, C107.2, C108.2, C109.2, C110.2, C111.2, C201.2, C202.2, C203.2, C204.2, C205.2, C301.2, C302.2, C304.2, C305.2, C306.2, C308.2, C309.2, C310.2, C311.2, C312.2, C315.2, C316.2, C401.2, C402.2, C403.2, C404.2, C405.2, C406.2, C407.2, C408.2, C409.2, C410.2, C501.2, C502.2, C505.2, C506.2, C507.2, C508.2, C601.2, C602.2, C603.2, C604.2, C605.2, C606.2, C701.2, C702.2, C703.2, C704.2, D302.2 (A), J101.2, J102.3, J103.2, J104.2, J104.4, J104.6, J104.14, J104.15, J105.1, J106.2, J107.1, J108.1, J108.3, J109.3, J110.A1 (GND), J110.A12 (GND), J110.B1 (GND), J110.B12 (GND), J110.SH (SHIELD), J112.2, J114.1, J114.3, J114.5, PS701.3 (-V), Q501.2 (S), Q701.2 (S), Q705.2 (S), Q706.2 (S), Q707.2 (S), R102.2, R223.2, R224.2, R226.2, R303.2, R304.2, R305.2, R306.2, R416.2, R502.2, R504.2, R506.2, R509.2, R510.2, R512.2, R514.2, R602.2, R603.2, R604.2, R703.2, R706.2, R708.2, R711.2, R713.2, R715.2, R717.2, R719.2, R722.2, R802.2, RT701.2, U101.15 (VSS), U101.27 (VSSA), U101.31 (VSS), U101.47 (VSS), U101.63 (VSS), U201.1 (GND), U201.40 (GND), U201.41 (EP_GND), U203.2 (GND), U301.4 (GND), U302.2 (GND), U303.4 (GND), U304.2 (GND), U501.7 (IMODE), U501.9 (PGND), U501.15 (GND), U501.16 (PMODE), U501.17 (EP), U502.2 (GND), U502.4 (IN-), U601.2 (GND), U602.4 (GND), U603.4 (GND), U604.4 (GND), U605.3 (GND), U606.3 (GND), U704.3 (GND), U704.4 (~ALERT), U704.7 (~OC)
/GRINDER_AC_FUSED: BR701.2 (AC1), F703.2
/GRINDER_AC_SWITCHED: F703.1, Q708.1 (A1), R728.2
/GRINDER_CURRENT_ADC: C407.1, R412.2, U101.20 (PA6)
/GRINDER_CURRENT_RAW: R412.1, U704.6 (VOUT)
/GRINDER_DC_MINUS: BR701.4 (-), C708.2, J115.3
/GRINDER_DC_PLUS: BR701.1 (+), U704.1 (IN+)
/GRINDER_DC_SENSED: C708.1, J115.1, U704.2 (IN-)
/GRINDER_EN_INTERLOCK: R718.1, U604.3 (2Y)
/GRINDER_EN_RAW: R717.1, U101.22 (PC4), U604.5 (2A)
/GRINDER_GATE_FEED: R721.2, U703.6 (MT_IN)
/GRINDER_LED_ANODE: R720.2, U703.1 (A)
/GRINDER_LED_GATE: Q707.1 (G), R718.2, R719.1
/GRINDER_LED_RETURN: Q707.3 (D), U703.2 (K)
/GRINDER_SNUBBER: C706.2, R728.1
/GRINDER_TRIAC_GATE: Q708.3 (G), U703.4 (MT_G)
/HEATER_AC_SWITCHED: J116.1, Q703.1 (A1)
/HEATER_EN_INTERLOCK: R707.1, U603.3 (2Y)
/HEATER_EN_RAW: R711.1, U101.23 (PC5), U603.5 (2A)
/HEATER_GATE_FEED: R710.2, U701.6 (MT_IN)
/HEATER_LED_ANODE: R709.2, U701.1 (A)
/HEATER_LED_GATE: Q705.1 (G), R707.2, R708.1
/HEATER_LED_RETURN: Q705.3 (D), U701.2 (K)
/HEATER_TRIAC_GATE: Q703.3 (G), U701.4 (MT_G)
/HS_NTC_ADC: C704.1, R726.2, RT701.1, U101.36 (PB14)
/KEY_INT_N: J104.13, U201.6 (IO6)
/KEY_SCL: J104.11, U201.5 (IO5)
/KEY_SDA: J104.12, U201.4 (IO4)
/LCD_BL_PWM: J104.10, R218.2
/LCD_CS_N: J104.7, R215.2
/LCD_DC: J104.8, R216.2
/LCD_MOSI: J104.5, R214.2
/LCD_RST_N: J104.9, R217.2
/LCD_SCLK: J104.3, R213.2
/LOAD_L_ENABLED: C705.1, C706.1, K701.4 (NO_A), K701.5 (NO_B), Q703.2 (A2), Q704.2 (A2), Q708.2 (A2), R710.1, R712.1, R721.1
/MAINS_ARM_RAW: R722.1, U101.60 (PB7), U603.1 (1A)
/MAINS_L_FUSED: C707.1, F701.2, F702.1, K701.3 (COM_A), K701.6 (COM_B), RV701.1
/MAINS_L_IN: F701.1, J118.1
/MAINS_N: BR701.3 (AC2), C707.2, J116.3, J117.2, J118.3, PS701.2 (AC/N), RV701.2
/MAINS_RELAY_EN: R801.1, U603.7 (1Y)
/MAINS_RELAY_GATE: Q701.1 (G), R801.2, R802.1
/MAINS_RELAY_RETURN: D701.2 (A), K701.8 (COIL_B), Q701.3 (D)
/MOSI_RAW: R214.1, U201.19 (IO11)
/NTC_ADC: C401.1, R402.2, U101.17 (PA3)
/NTC_RAW: J105.2, R401.2, R402.1
/PROBE_3V3: J114.2, R723.2
/PROBE_12V: J114.4, R724.2
/PROBE_24V: J114.6, R725.2
/PROTECTIVE_EARTH: J119.1, J120.1
/PSU_L_FUSED: F702.2, PS701.1 (AC/L)
/PUMP_AC_SWITCHED: J117.1, Q704.1 (A1), R727.2
/PUMP_EN_INTERLOCK: R714.1, U604.7 (1Y)
/PUMP_EN_RAW: R713.1, U101.33 (PB11), U604.1 (1A)
/PUMP_GATE_FEED: R712.2, U702.6 (MT_IN)
/PUMP_LED_ANODE: R716.2, U702.1 (A)
/PUMP_LED_GATE: Q706.1 (G), R714.2, R715.1
/PUMP_LED_RETURN: Q706.3 (D), U702.2 (K)
/PUMP_SNUBBER: C705.2, R727.1
/PUMP_TRIAC_GATE: Q704.3 (G), U702.4 (MT_G)
/RAIL_12V_ADC: C701.1, R702.2, R703.1, U101.6 (PF1)
/RAIL_12V_DIV: R701.2, R702.1
/RAIL_24V_ADC: C702.1, R705.2, R706.1, U101.9 (PC1)
/RAIL_24V_DIV: R704.2, R705.1
/RST_RAW: R217.1, U201.12 (IO8)
/SCLK_RAW: R213.1, U201.20 (IO12)
/STM_BOOT0: R102.1, U101.61 (PB8)
/STM_NRST: C101.1, J102.5, R101.2, U101.7 (NRST), U601.1 (~RESET), U605.2 (A), U606.1 (A)
/STM_NRST_BUF: U602.2 (1B), U602.6 (2B), U603.2 (1B), U603.6 (2B), U604.2 (1B), U604.6 (2B), U605.4 (Y)
/STM_SWCLK: J102.4, U101.50 (PA14)
/STM_SWDIO: J102.2, U101.49 (PA13)
/STM_SWO: J102.6, U101.56 (PB3)
/STM_TO_ESP: R211.2, U201.38 (IO2)
/STM_TX_RAW: R211.1, U101.43 (PA9)
/SW_NODE: C303.2, L301.1, U301.5 (SW)
/UI_ILIM: R304.1, U302.5 (ILIM)
/UI_PWR_EN: R301.2, U101.34 (PB12), U302.3 (EN)
/USB_BENCH_ENABLE: D303.2 (A), J111.2
/USB_CC1: J110.A5 (CC1), R223.1
/USB_CC2: J110.B5 (CC2), R224.1
/USB_DM_DEVICE: R221.1, U203.4 (I/O2)
/USB_DM_PORT: J110.A7 (D-), J110.B7 (D-), U203.3 (I/O2)
/USB_DM_RAW: R221.2, U201.13 (IO19)
/USB_DP_DEVICE: R222.1, U203.6 (I/O1)
/USB_DP_PORT: J110.A6 (D+), J110.B6 (D+), U203.1 (I/O1)
/USB_DP_RAW: R222.2, U201.14 (IO20)
/USB_VBUS: C205.1, F302.1, J110.A4 (VBUS), J110.A9 (VBUS), J110.B4 (VBUS), J110.B9 (VBUS), R225.1, U203.5 (VBUS)
/USB_VBUS_FUSED: F302.2, J111.1
/USB_VBUS_SENSE: C204.1, R225.2, R226.1, U201.8 (IO15)
/VALVE_EN_DRV: R511.2, R512.1, U502.3 (IN+)
/VALVE_EN_INTERLOCK: R511.1, U602.3 (2Y)
/VALVE_EN_RAW: R604.1, U101.21 (PA7), U602.5 (2A)
/VALVE_GATE: Q501.1 (G), R513.2, R514.1
/VALVE_GATE_RAW: R513.1, U502.5 (OUT)
/VALVE_RETURN: D306.2 (A), J113.4, Q501.3 (D)
/WATCHDOG_KICK: R601.2, R602.1, U606.2 (B)
/WATCHDOG_KICK_RAW: R601.1, U101.57 (PB4)
/WATCHDOG_WDI: U601.4 (WDI), U606.4 (Y)
/WATER_ILIM: R306.1, U304.5 (ILIM)
/WATER_LEVEL: C406.1, R411.2, U101.11 (PC3)
/WATER_RAW: J109.2, R411.1, R415.2, R416.1
/WATER_VCC: C410.1, J109.1, R415.1, U304.6 (OUT)

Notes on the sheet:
OPEN SAECO / PRINCIPAL — REV A
BORRADOR: lógica, USB, sensores, cargas de 24V y de red y fuente IRM-30 en la misma placa. Sin ensayar.
01 / STM32 de control — C431633
NC = pin sin asignar; no equivale a ninguna vía del arnés Saeco.
Reloj HSI interno. USART1 PA9/PA10, AF7. VREFBUF interno deshabilitado.
02 / ESP32 de interfaz, antena externa U.FL — C2980300
GPIO35/36/37 reservados PSRAM. USB nativo en GPIO19/20; GPIO15 detecta VBUS.
03 / Conexiones internas y programación
J102/J103 pinout propio; 3V3 es referencia, no alimentar desde el programador.
J101 recibe 12V DC aislados. Nunca conectar a red.
04 / Reset y arranque
EN/BOOT accesibles por J103. BOOT0 STM: opción de arranque por SWD pendiente.
05 / UART entre MCU y resistencias de origen SPI
UART cruzada. 33 ohm candidato, ajustar con flancos y arnés real.
06 / Desacoplo — colocar junto al pin indicado, comprobar capacitancia efectiva
07 / Entrada aislada protegida y buck 3V3 — AP63203, 2A
Fusible + bloqueo de polaridad + TVS. J101 entra por F305/D307, en OR con U303 por F301/D301.
J101 solo desde una fuente AC/DC aislada y certificada; en la máquina los 12V salen de U303 (hoja 15).
08 / Corte y limitación del frontal — TPS2553, 0,5 A
PB12 controla UI_PWR_EN; pull-up mantiene el frontal encendido durante reset.
ILIM 475-565 mA y apagado térmico; R305 descarga el frontal al apagarlo. FAULT sin conectar.
09 / USB-C de servicio — datos ESP32 y alimentación de banco opcional
GPIO19=D-, GPIO20=D+. R221/R222 junto al ESP; par diferencial 90 ohm y misma longitud.
J111 se fabrica ABIERTO. Cerrarlo solo en banco: USB limitado a 500mA alimenta el buck; no cargas.
10 / Entradas pasivas — JP13 y JP5 HR A2506; resto, huellas candidatas por foto
PA3 ADC1_IN4. NTC a masa; abierto≈3V3, corto≈0V. Usar tabla del manual.
PA2 TIM2_CH3. Pin 1 señal, 2 GND, 3 VCC; pin 1 es pad cuadrado/izquierda en vista cenital.
Digmesa 932-9521-B: NPN OC, 3,8–20V. VCC=12V por R413 (390 Ω); pull-up separado a 3V3.
PA1: 0=cajón y puerta colocados; 1=abierto. Medido sin tensión.
PC2 (presencia) / PA0 (trabajo) activos a 0. V1 rojo=OUT1, V2 azul=OUT2, V3/V4 puente,
V5/V6 verde presencia, V7/V8 rojo trabajo: V1..V8 en los pads 8..1, V1 junto a JP21.
PA6 ADC2_IN3: corriente del molinillo, 1,65 V + 0,1 V/A (U704, etapa 18).
PC3 ADC12_IN9/GPIO. Pin 1 rojo=3V3, 2 blanco=señal, 3 negro=GND; salida por caracterizar.
11 / Motor del grupo 24V — DRV8876, PH/EN, límite candidato 1A
PF0 PWM (TIM1_CH3N), PC14 dirección, PB5 nSLEEP, PB6 nFAULT, PC0 ADC. PMODE/IMODE a GND.
R510 y divisor R508/R509 fijan ITRIP≈1A; validar corriente, térmica, bulk y frenado.
J112 exige 24V DC aislados y limitados; F306/D308 la protegen contra polaridad inversa. Sobretensión pendiente.
12 / Electroválvula 24V — low-side, fusible propio y rueda libre
JP3.1=+24V, JP3.2=retorno conmutado; JP3.3–5 sin uso. PA7 gobierna U502.
D306 es obligatoria: la medida 0,073V en ambos sentidos no demuestra diodo interno polarizado.

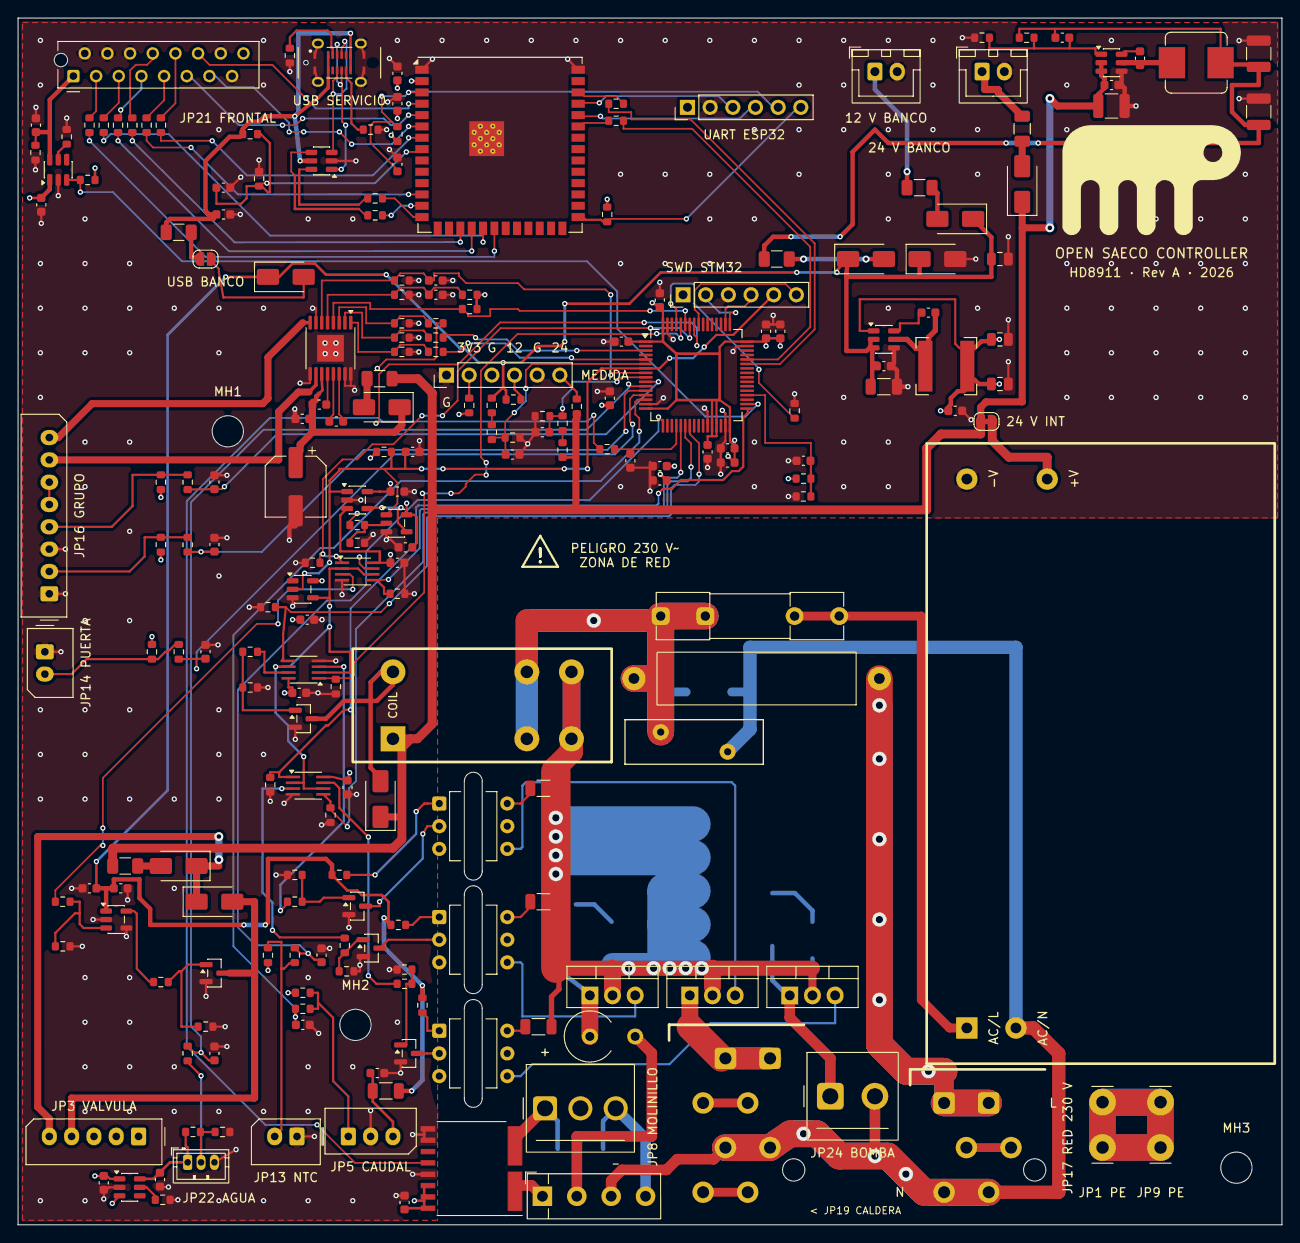
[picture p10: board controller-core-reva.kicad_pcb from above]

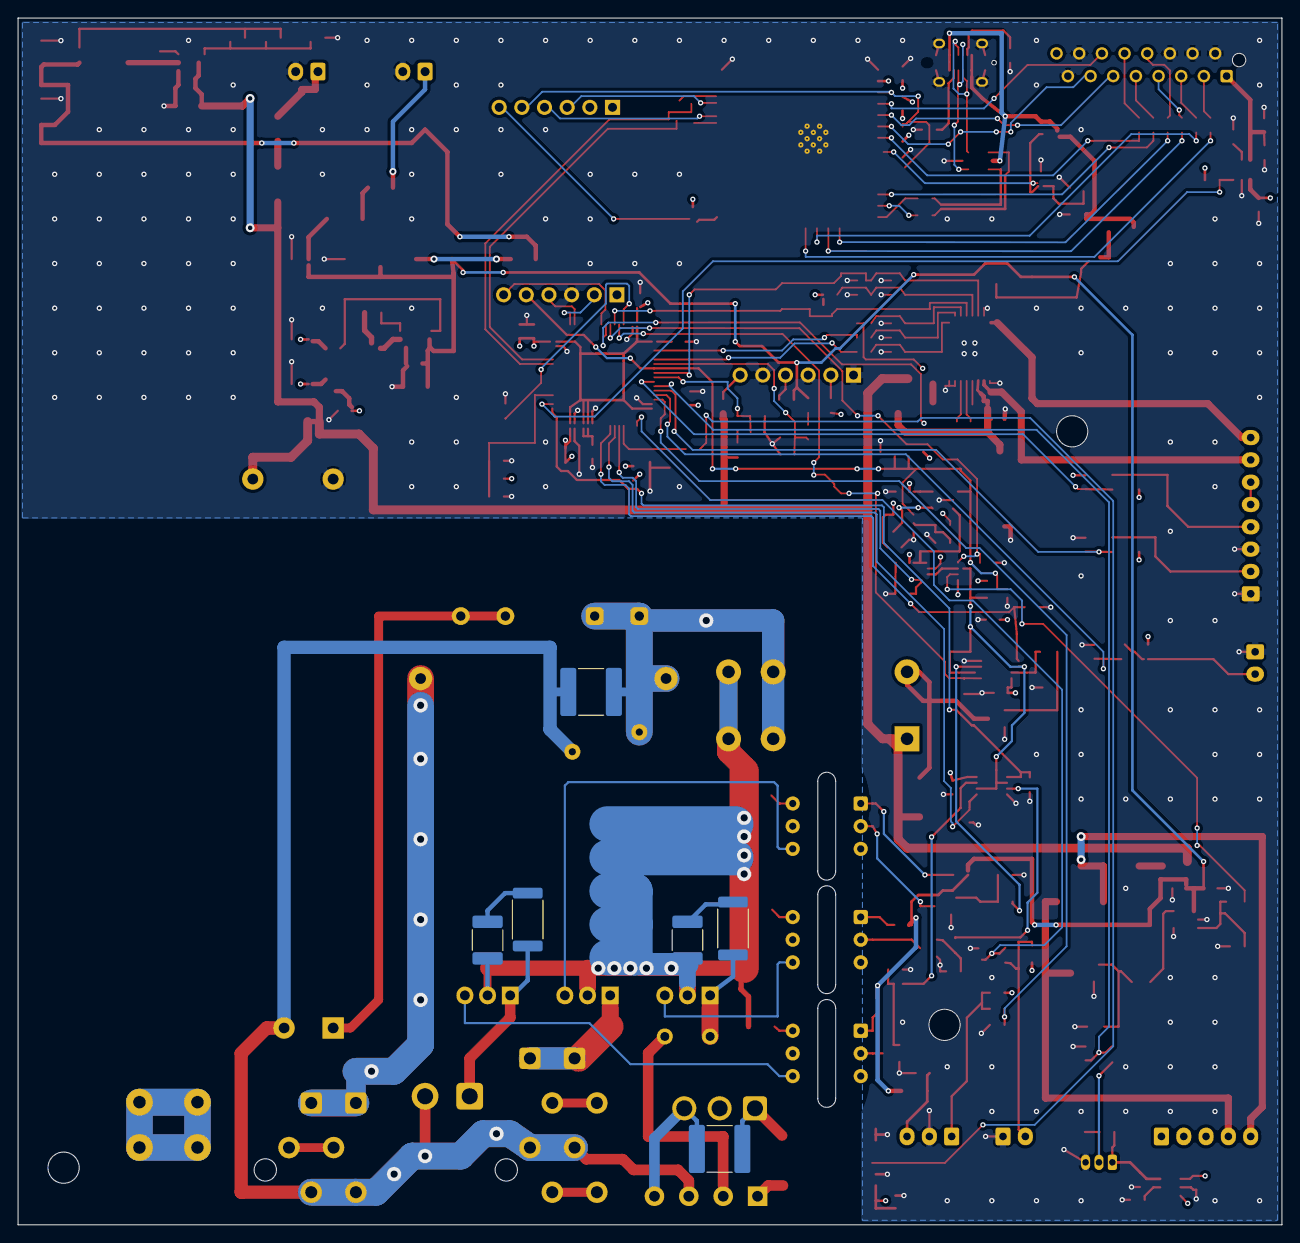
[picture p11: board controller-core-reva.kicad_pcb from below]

Board: 4 copper layers, 141.6 x 135.2 mm, 226 parts (6 on the bottom side), 154 nets.

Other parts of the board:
MH1, MH2, MH3: PHOTO-DERIVED 3.5mm NPTH; MountingHole_3.5mm

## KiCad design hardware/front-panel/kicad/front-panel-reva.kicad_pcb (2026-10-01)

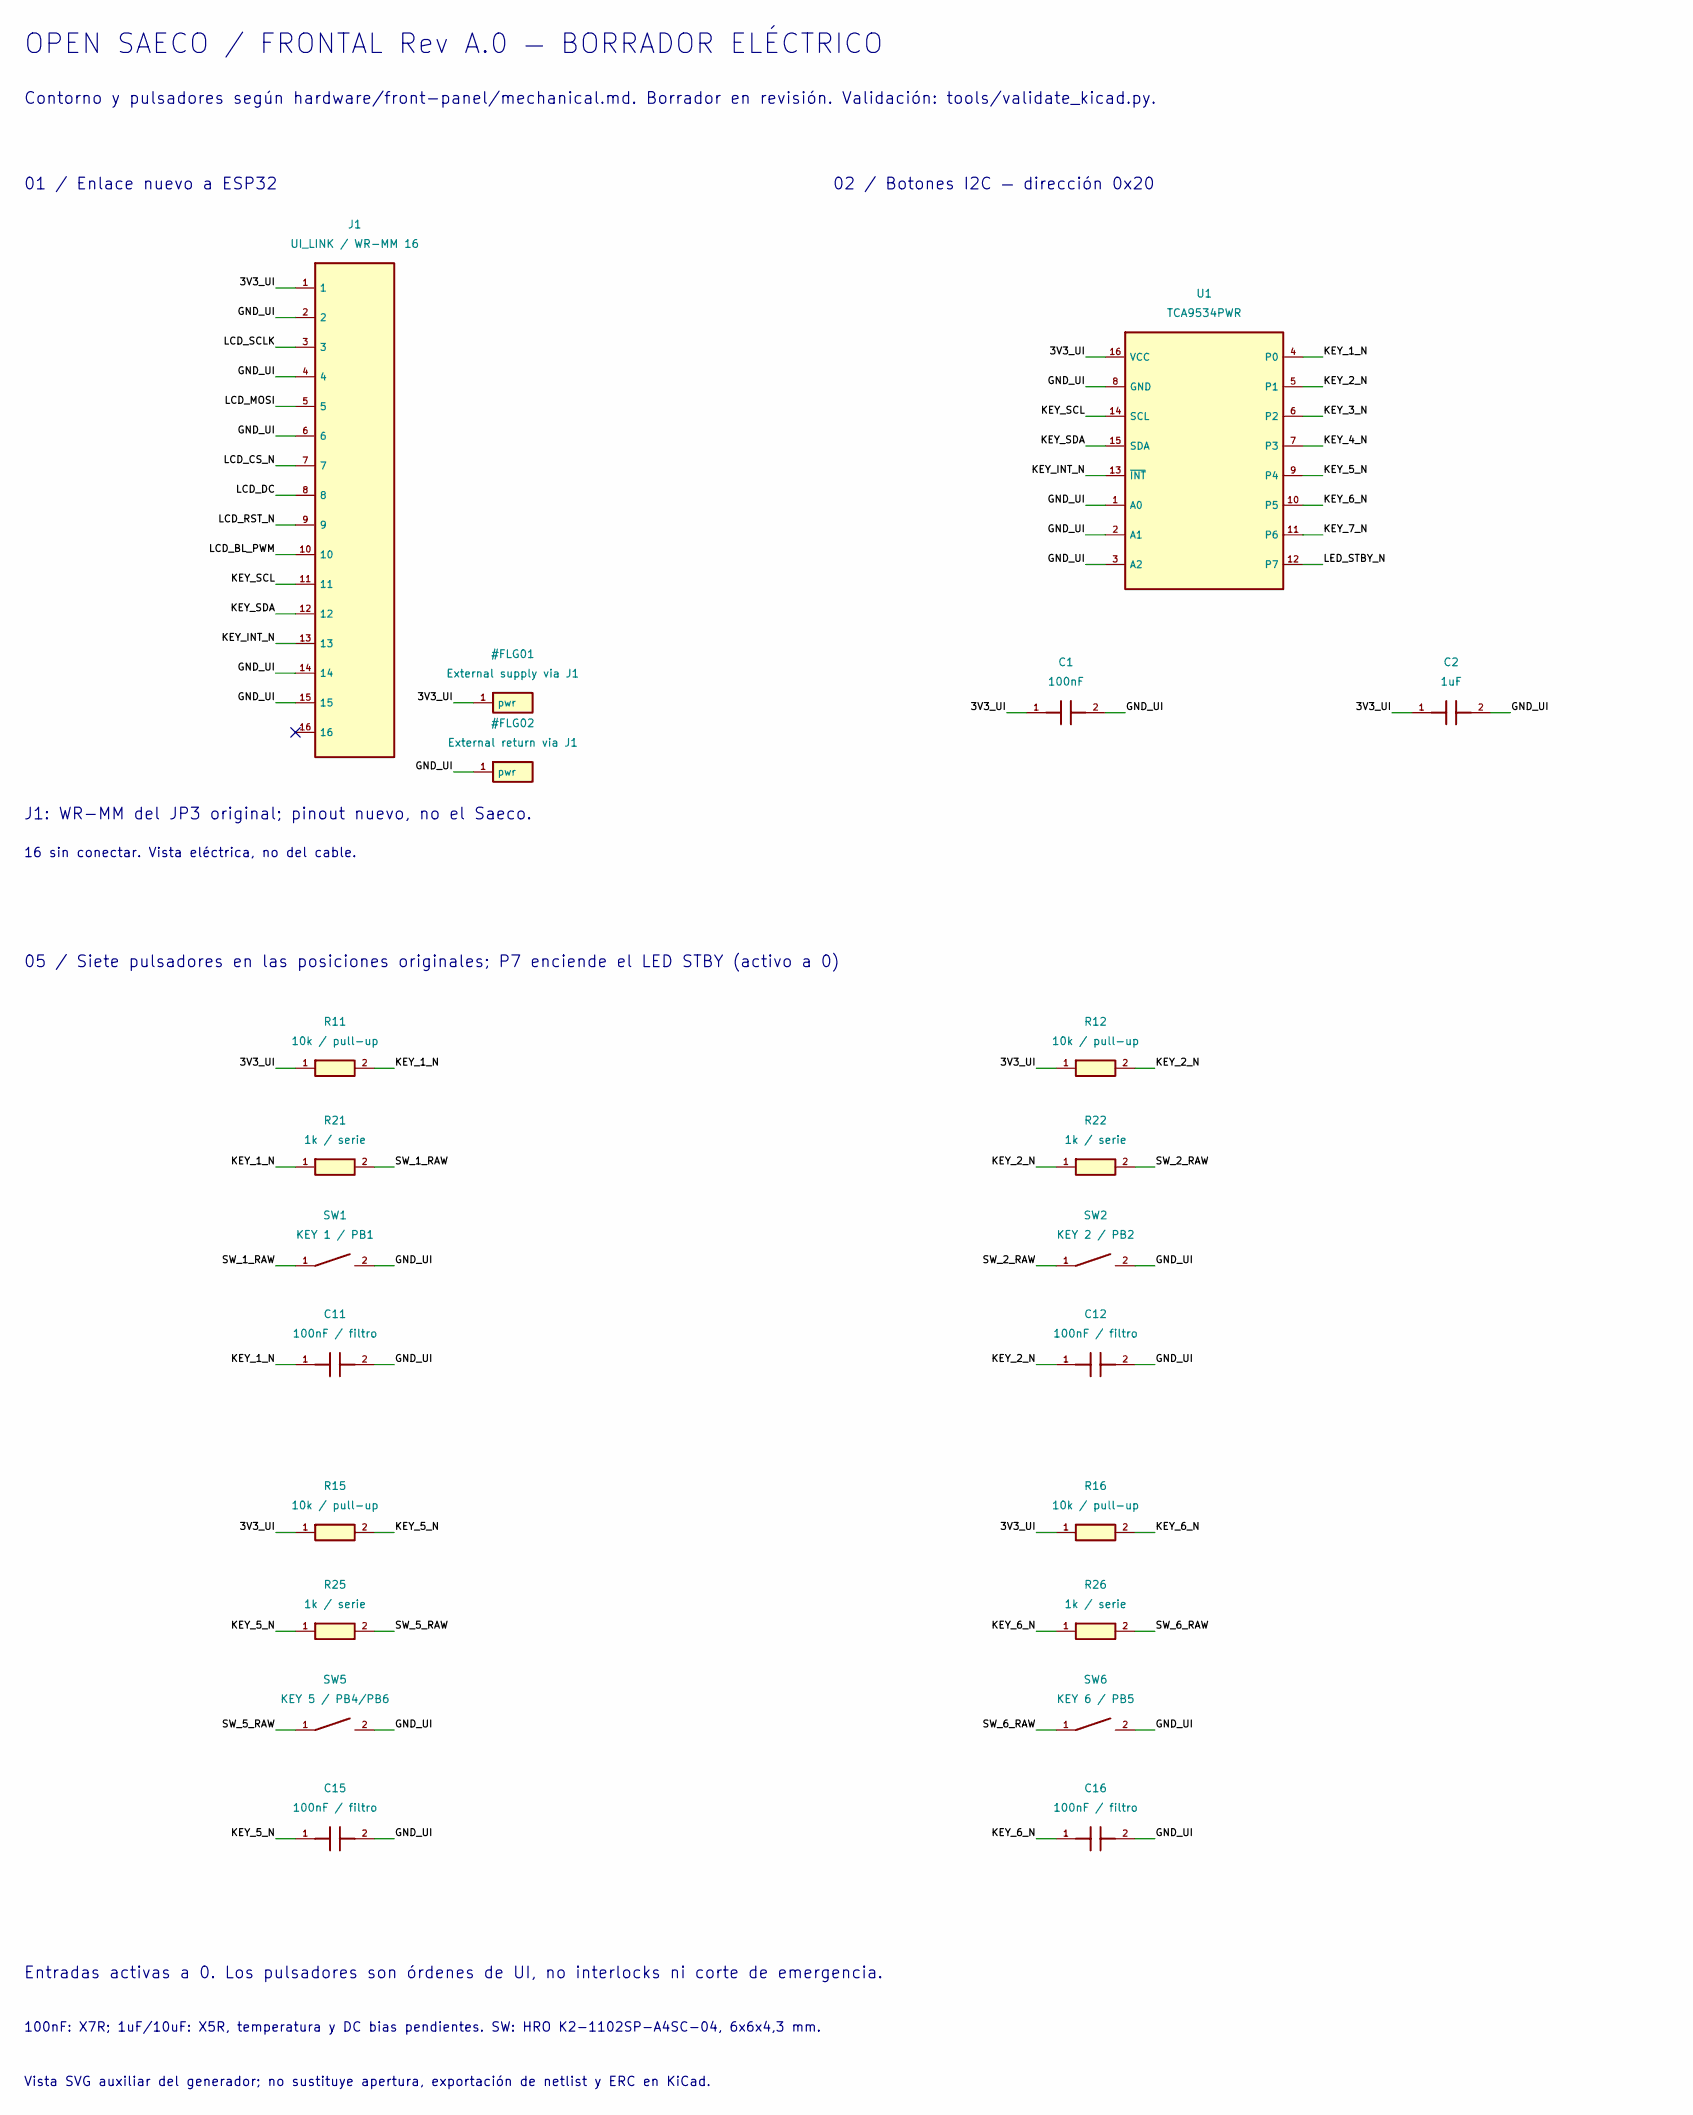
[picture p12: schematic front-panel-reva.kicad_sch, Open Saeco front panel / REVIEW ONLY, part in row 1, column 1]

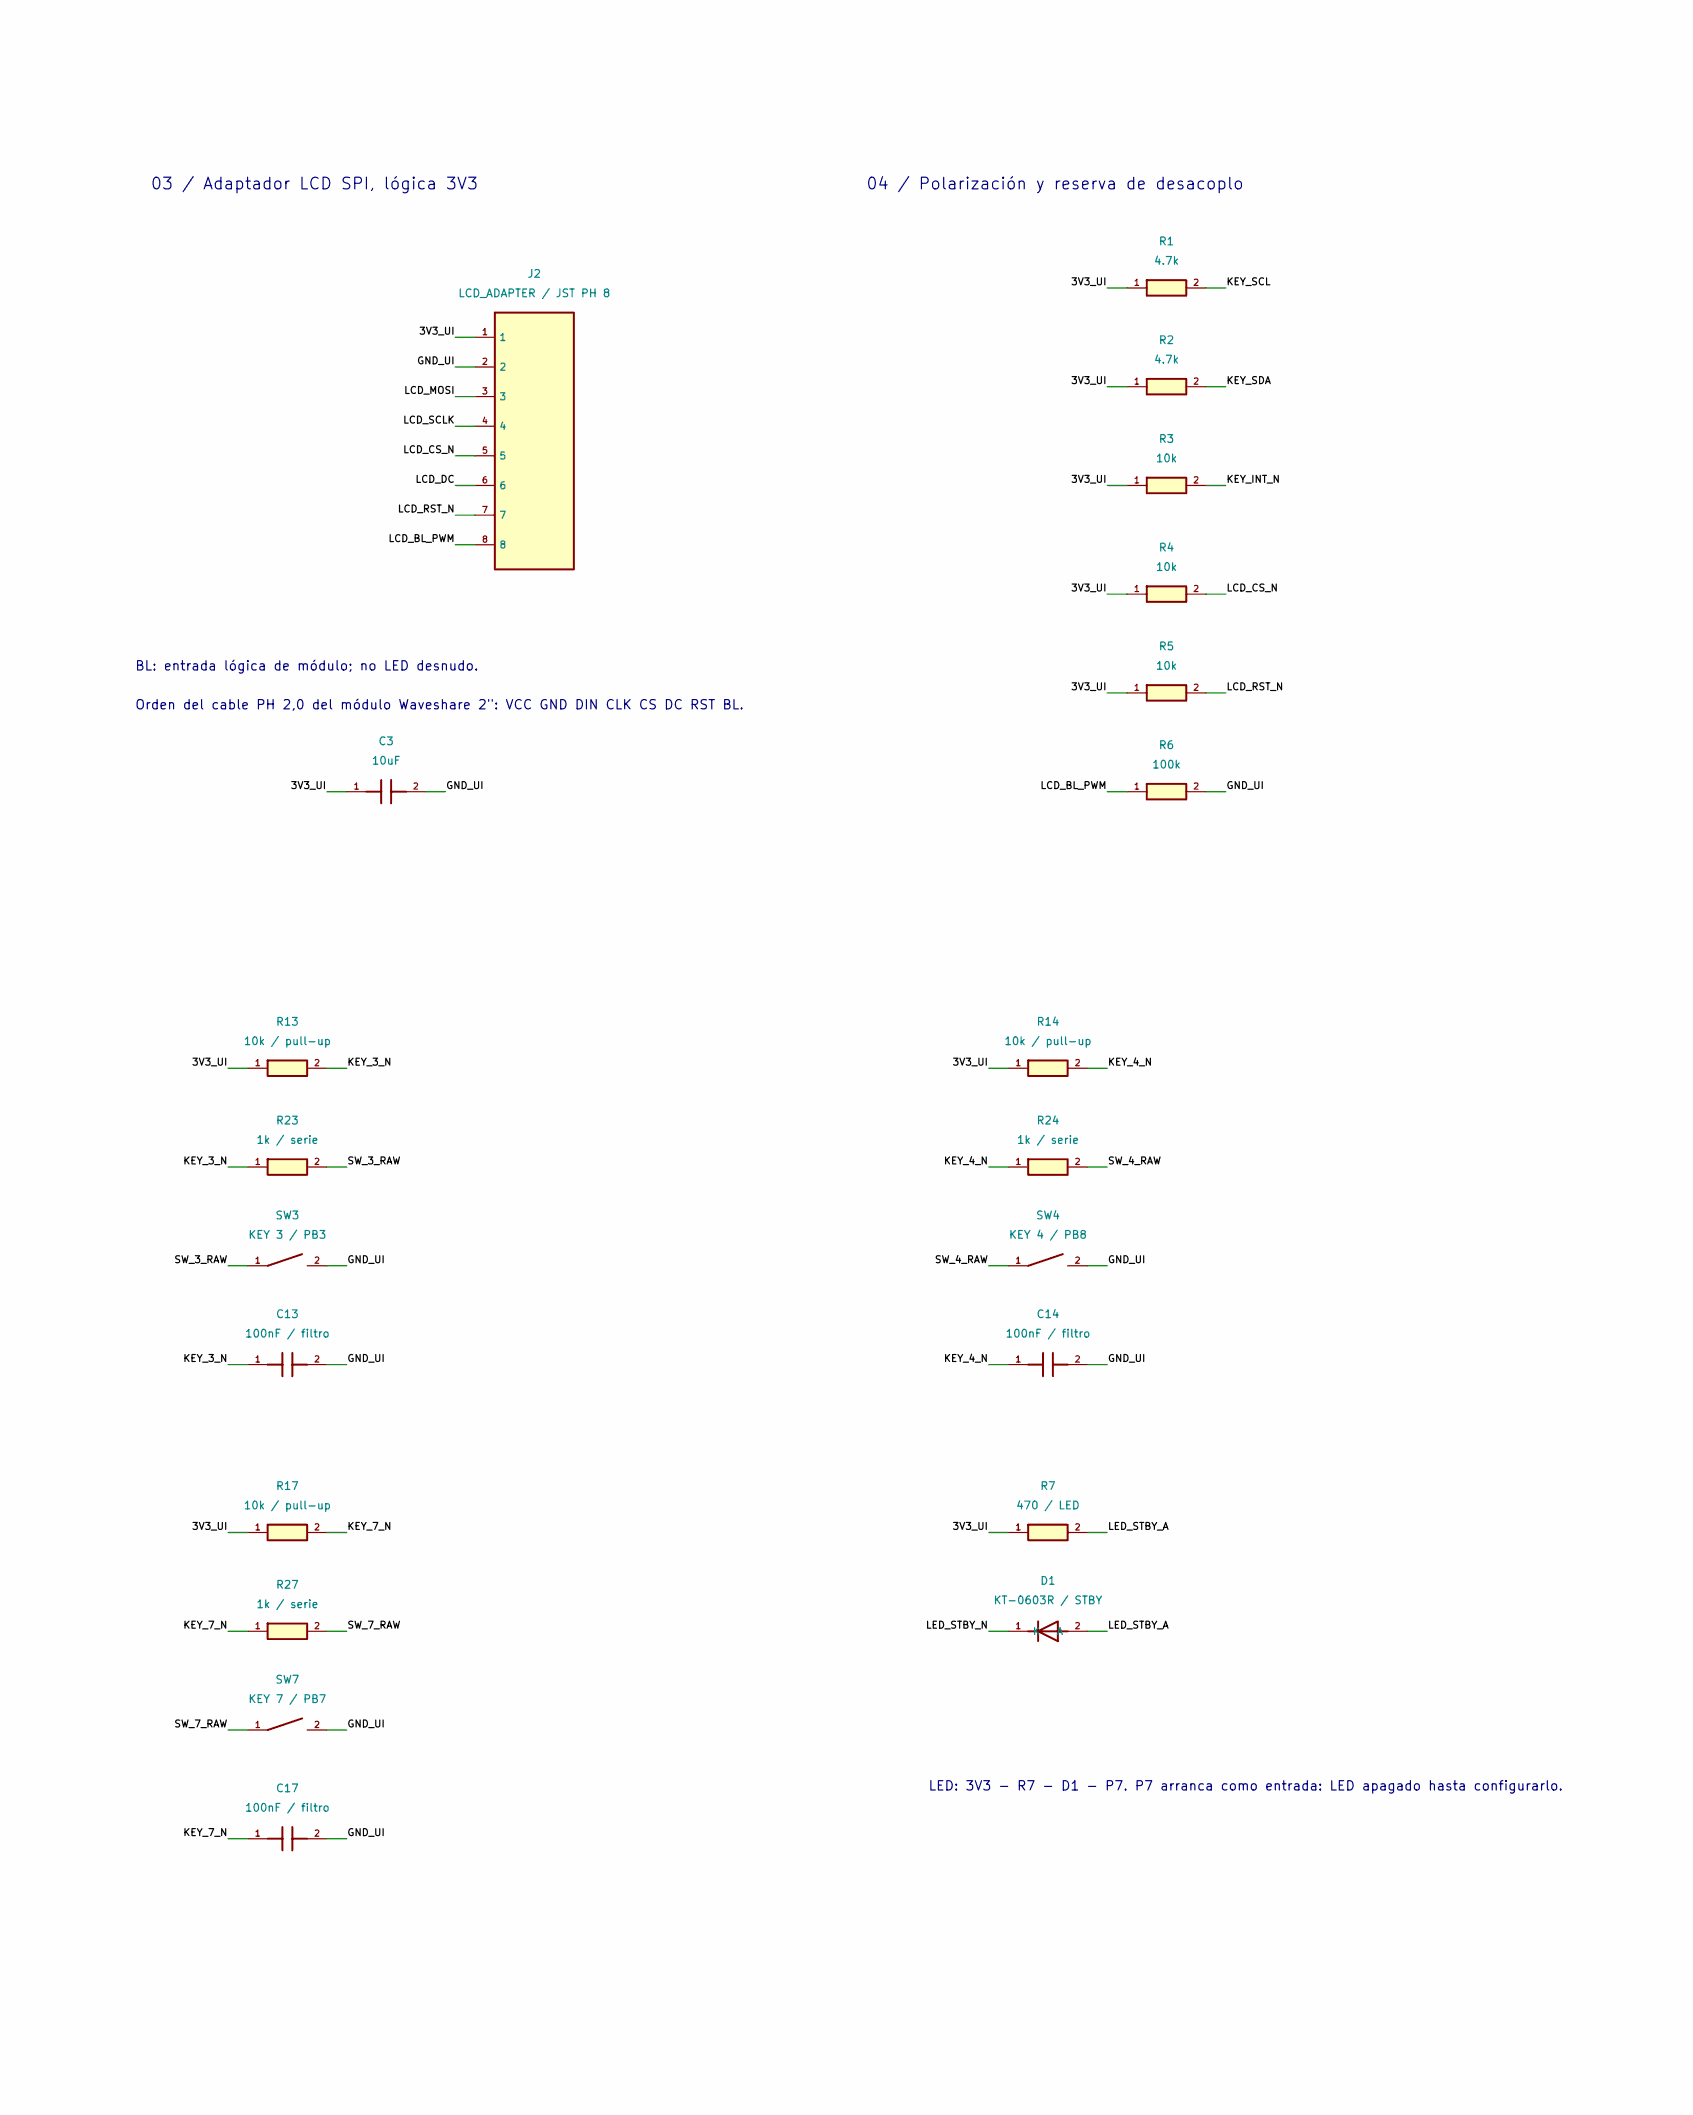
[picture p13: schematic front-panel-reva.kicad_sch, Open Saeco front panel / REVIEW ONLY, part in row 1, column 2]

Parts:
C1: 100nF; C_0603_1608Metric; mpn CC0603KRX7R9BB104; lcsc C14663
C2: 1uF; C_0603_1608Metric; mpn CL10A105KB8NNNC; lcsc C15849
C3: 10uF; C_0603_1608Metric; mpn CL10A106MA8NRNC; lcsc C96446
C11, C12, C13, C14, C15, C16, C17: 100nF / filtro; C_0603_1608Metric; mpn CC0603KRX7R9BB104; lcsc C14663
D1: KT-0603R / STBY; LED_0603_1608Metric; mpn KT-0603R; lcsc C2286
J1: UI_LINK / WR-MM 16; Wurth_WR-MM_690367181672_2x08_P1.27mm_Vertical; mpn 690367181672; lcsc C19103863
J2: LCD_ADAPTER / JST PH 8; JST_PH_B8B-PH-K_1x08_P2.00mm_Vertical; mpn B8B-PH-K-S(LF)(SN); lcsc C157974
R1, R2: 4.7k; R_0603_1608Metric; mpn 0603WAF4701T5E; lcsc C23162
R3, R4, R5: 10k; R_0603_1608Metric; mpn 0603WAF1002T5E; lcsc C25804
R6: 100k; R_0603_1608Metric; mpn 0603WAF1003T5E; lcsc C25803
R7: 470 / LED; R_0603_1608Metric; mpn 0603WAF4700T5E; lcsc C23179
R11, R12, R13, R14, R15, R16, R17: 10k / pull-up; R_0603_1608Metric; mpn 0603WAF1002T5E; lcsc C25804
R21, R22, R23, R24, R25, R26, R27: 1k / serie; R_0603_1608Metric; mpn 0603WAF1001T5E; lcsc C21190
SW1: KEY 1 / PB1; SW_HRO_K2-1102SP-A4SC-04; mpn K2-1102SP-A4SC-04; lcsc C83916
SW2: KEY 2 / PB2; SW_HRO_K2-1102SP-A4SC-04; mpn K2-1102SP-A4SC-04; lcsc C83916
SW3: KEY 3 / PB3; SW_HRO_K2-1102SP-A4SC-04; mpn K2-1102SP-A4SC-04; lcsc C83916
SW4: KEY 4 / PB8; SW_HRO_K2-1102SP-A4SC-04; mpn K2-1102SP-A4SC-04; lcsc C83916
SW5: KEY 5 / PB4/PB6; SW_HRO_K2-1102SP-A4SC-04; mpn K2-1102SP-A4SC-04; lcsc C83916
SW6: KEY 6 / PB5; SW_HRO_K2-1102SP-A4SC-04; mpn K2-1102SP-A4SC-04; lcsc C83916
SW7: KEY 7 / PB7; SW_HRO_K2-1102SP-A4SC-04; mpn K2-1102SP-A4SC-04; lcsc C83916
U1: TCA9534PWR; TSSOP-16_4.4x5mm_P0.65mm; mpn TCA9534PWR; lcsc C783615

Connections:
/3V3_UI: C1.1, C2.1, C3.1, J1.1, J2.1, R1.1, R2.1, R3.1, R4.1, R5.1, R7.1, R11.1, R12.1, R13.1, R14.1, R15.1, R16.1, R17.1, U1.16 (VCC)
/GND_UI: C1.2, C2.2, C3.2, C11.2, C12.2, C13.2, C14.2, C15.2, C16.2, C17.2, J1.2, J1.4, J1.6, J1.14, J1.15, J2.2, R6.2, SW1.2, SW2.2, SW3.2, SW4.2, SW5.2, SW6.2, SW7.2, U1.1 (A0), U1.2 (A1), U1.3 (A2), U1.8 (GND)
/KEY_1_N: C11.1, R11.2, R21.1, U1.4 (P0)
/KEY_2_N: C12.1, R12.2, R22.1, U1.5 (P1)
/KEY_3_N: C13.1, R13.2, R23.1, U1.6 (P2)
/KEY_4_N: C14.1, R14.2, R24.1, U1.7 (P3)
/KEY_5_N: C15.1, R15.2, R25.1, U1.9 (P4)
/KEY_6_N: C16.1, R16.2, R26.1, U1.10 (P5)
/KEY_7_N: C17.1, R17.2, R27.1, U1.11 (P6)
/KEY_INT_N: J1.13, R3.2, U1.13 (~INT)
/KEY_SCL: J1.11, R1.2, U1.14 (SCL)
/KEY_SDA: J1.12, R2.2, U1.15 (SDA)
/LCD_BL_PWM: J1.10, J2.8, R6.1
/LCD_CS_N: J1.7, J2.5, R4.2
/LCD_DC: J1.8, J2.6
/LCD_MOSI: J1.5, J2.3
/LCD_RST_N: J1.9, J2.7, R5.2
/LCD_SCLK: J1.3, J2.4
/LED_STBY_A: D1.2 (A), R7.2
/LED_STBY_N: D1.1 (K), U1.12 (P7)
/SW_1_RAW: R21.2, SW1.1
/SW_2_RAW: R22.2, SW2.1
/SW_3_RAW: R23.2, SW3.1
/SW_4_RAW: R24.2, SW4.1
/SW_5_RAW: R25.2, SW5.1
/SW_6_RAW: R26.2, SW6.1
/SW_7_RAW: R27.2, SW7.1

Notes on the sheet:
OPEN SAECO / FRONTAL Rev A.0 — BORRADOR ELÉCTRICO
Contorno y pulsadores según hardware/front-panel/mechanical.md. Borrador en revisión. Validación: tools/validate_kicad.py.
01 / Enlace nuevo a ESP32
J1: WR-MM del JP3 original; pinout nuevo, no el Saeco.
16 sin conectar. Vista eléctrica, no del cable.
02 / Botones I2C — dirección 0x20
03 / Adaptador LCD SPI, lógica 3V3
Orden del cable PH 2,0 del módulo Waveshare 2": VCC GND DIN CLK CS DC RST BL.
BL: entrada lógica de módulo; no LED desnudo.
04 / Polarización y reserva de desacoplo
05 / Siete pulsadores en las posiciones originales; P7 enciende el LED STBY (activo a 0)
LED: 3V3 - R7 - D1 - P7. P7 arranca como entrada: LED apagado hasta configurarlo.
Entradas activas a 0. Los pulsadores son órdenes de UI, no interlocks ni corte de emergencia.
100nF: X7R; 1uF/10uF: X5R, temperatura y DC bias pendientes. SW: HRO K2-1102SP-A4SC-04, 6x6x4,3 mm.
Vista SVG auxiliar del generador; no sustituye apertura, exportación de netlist y ERC en KiCad.

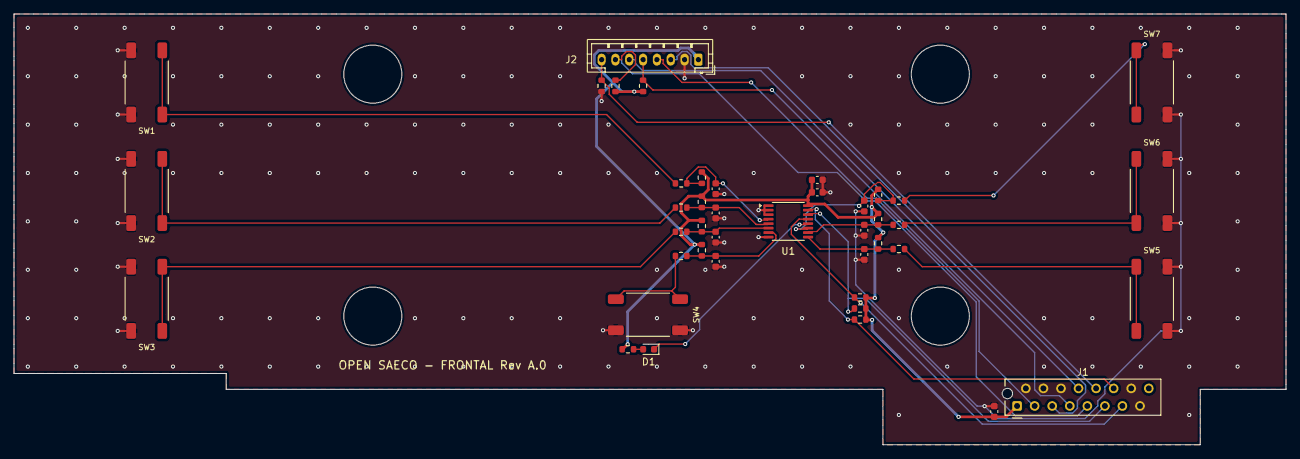
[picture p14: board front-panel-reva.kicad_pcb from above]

Board: 2 copper layers, 184.0 x 62.3 mm, 42 parts (0 on the bottom side), 27 nets.

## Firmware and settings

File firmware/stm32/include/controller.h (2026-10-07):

/* SPDX-License-Identifier: MIT */
#ifndef OSC_CONTROLLER_H
#define OSC_CONTROLLER_H
#include <stdbool.h>
typedef enum { OSC_BOOT, OSC_SAFE_IDLE, OSC_FAULT } osc_state;
typedef enum { OSC_REJECTED_NOT_IMPLEMENTED } osc_result;
/* brew_forward drives the unit toward the work position; mains arms K701
 * on its own (the BSP also arms it for heater, pump and grinder). */
typedef struct { bool heater, pump, valve, grinder, brew_motor, brew_forward, mains; } osc_outputs;
typedef struct { osc_state state; osc_outputs outputs; } osc_controller;
void osc_init(osc_controller *c);
void osc_tick(osc_controller *c, bool interlocks_ok, bool link_ok);
void osc_stop(osc_controller *c);
osc_result osc_start(osc_controller *c);
/* Leaves OSC_FAULT for OSC_SAFE_IDLE only when the interlocks and the link
 * are both good again; returns whether it did. */
bool osc_clear_fault(osc_controller *c, bool interlocks_ok, bool link_ok);
/* Load sharing on the relay-switched phase (hardware/power/power-architecture.md).
 * Heater 8.4 A plus a grinder sized for 3 A would draw 11.6 A through F701
 * (T10A) and JP17 (10 A per VH contact). While the grinder runs the heater
 * conducts at most 3 whole mains cycles in every window of 5: 8.4 A x
 * sqrt(0.6) = 6.5 A, 9.7 A with grinder and pump. Each grind lasts at most
 * OSC_GRINDER_MAX_ON_MS, the most BR701 takes at 3 A without a pause. */
#define OSC_HEATER_WINDOW_CYCLES 5u
#define OSC_HEATER_CYCLES_WHILE_GRINDING 3u
#define OSC_GRINDER_MAX_ON_MS 10000u
unsigned osc_heater_cycles_allowed(bool grinder_on);

/* Heater triac derating (issue #2, hardware/power/power-architecture.md).
 * The heatsink only reaches about 8 K/W in the volume it has, so the heater
 * cannot conduct continuously with warm air inside the machine: at 253 V it
 * dissipates 8.4 W in Q703 and the junction would pass 125 C above 39 C of
 * air. A first-order model of the profile, fed by the air temperature RT701
 * reads above it and by the power each triac dissipates, estimates the
 * junction at full heater power; above OSC_TJ_DERATE_C the heater loses
 * cycles of the window, down to none at OSC_TJ_CUTOFF_C. Rth and the heat
 * capacity are ASSUMED until TH-03 measures them in a descaling run. */
#define OSC_HS_RTH_HA_C_PER_W 8.0f    /* profile to air, catalogue class for the volume */
#define OSC_HS_RTH_JH_C_PER_W 2.2f    /* BTA24 junction to case 1.7 + greased interface 0.5 */
#define OSC_HS_CAPACITY_J_PER_C 30.0f /* about 33 g of aluminium */
#define OSC_HEATER_TRIAC_W 8.4f       /* 9.2 A at 253 V */
#define OSC_PUMP_TRIAC_W 0.3f
#define OSC_GRINDER_TRIAC_W 2.5f
#define OSC_TJ_DERATE_C 105.0f
#define OSC_TJ_CUTOFF_C 120.0f
#define OSC_HS_AIR_FALLBACK_C 70.0f   /* RT701 open or shorted: assume hot air */
typedef struct { float heatsink_c; bool primed; } osc_heatsink;
void osc_heatsink_init(osc_heatsink *h);
/* air_ok false (RT701 out of its window) uses the fallback air temperature.
 * heater_frac is the share of cycles the heater conducted over dt_s. */
void osc_heatsink_step(osc_heatsink *h, float air_c, bool air_ok, float heater_frac,
                       bool pump_on, bool grinder_on, float dt_s);
/* Heater triac junction if the heater conducted every cycle from now on. */
float osc_heater_junction_full_c(const osc_heatsink *h);
/* Cycles of OSC_HEATER_WINDOW_CYCLES the heater may conduct; the caller
 * takes the lower of this and osc_heater_cycles_allowed(). */
unsigned osc_heater_cycles_thermal(const osc_heatsink *h);

/* Grinder current through U704 (hardware/power/power-architecture.md): the
 * original machine reads it to tell an empty hopper (the motor runs light)
 * from jammed burrs (it stalls). Means over 100 ms blocks after the inrush.
 * Thresholds ASSUMED until GR-02, GR-03 and GR-08 measure the motor: the
 * stall is 230 V x 0.9 / 68 Ohm = 3.0 A mean, and the stage is checked for
 * a running current up to 1.5 A. */
#define OSC_GRINDER_START_MS 300u
#define OSC_GRINDER_BLOCK_MS 100u
#define OSC_GRINDER_JAM_MA 2000
#define OSC_GRINDER_EMPTY_MA 550
#define OSC_GRINDER_EMPTY_DROP_PCT 75   /* of the current loaded at the start */
#define OSC_GRINDER_EMPTY_BLOCKS 2u     /* consecutive light blocks */
typedef enum { OSC_GRIND_OK = 0, OSC_GRIND_EMPTY = 1, OSC_GRIND_JAM = 2 } osc_grind_verdict;
/* mean_ma: one block; loaded_ma: the reference from the first loaded blocks,
 * 0 while there is none. */
osc_grind_verdict osc_grinder_verdict(int mean_ma, int loaded_ma);

/* Brew-unit compression: with ground coffee in the chamber the current at
 * the work stop rises over the running current I0 (manual: I0 + 55 to
 * 200 mA); an empty chamber barely raises it. ASSUMED until BU-05. */
#define OSC_DOSE_MIN_RISE_MA 40
bool osc_dose_present(int i0_ma, int stop_ma);
#endif

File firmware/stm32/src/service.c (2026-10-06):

/* SPDX-License-Identifier: MIT */
#include "service.h"
#include <string.h>

static void off(osc_service *s) { memset(&s->out, 0, sizeof s->out); }

void svc_init(osc_service *s) { memset(s, 0, sizeof *s); }

bool svc_running(const osc_service *s) { return s->r.phase == OSC_TEST_RUNNING; }

bool svc_drives(const osc_service *s) { return s->r.id != OSC_TEST_INPUTS && s->r.id != OSC_TEST_NONE; }

static bool needs_door(uint8_t id) {
    return id == OSC_TEST_BREW_UNIT || id == OSC_TEST_PUMP || id == OSC_TEST_HEATER ||
           id == OSC_TEST_GRINDER || id == OSC_TEST_DOSE;
}

static bool moves_unit(uint8_t id) { return id == OSC_TEST_BREW_UNIT || id == OSC_TEST_DOSE; }

static void finish(osc_service *s, osc_test_phase phase, osc_test_reason why, uint32_t now) {
    off(s);
    s->r.phase = (uint8_t)phase;
    s->r.reason = (uint8_t)why;
    s->r.elapsed_ms = now - s->t0;
}

void svc_abort(osc_service *s, osc_test_reason why, uint32_t now) {
    if (svc_running(s)) finish(s, OSC_TEST_ABORTED, why, now);
}

static void next(osc_service *s, uint32_t now) {
    s->r.step++;
    s->t_step = now;
}

osc_test_reason svc_start(osc_service *s, uint8_t id, uint16_t param, const osc_inputs *in,
                          bool core_idle, uint32_t now) {
    osc_test_reason why = OSC_REASON_OK;
    if (id == OSC_TEST_NONE || id >= OSC_TEST_COUNT) why = OSC_REASON_UNKNOWN;
    else if (svc_running(s)) why = OSC_REASON_STATE;
    else if (id != OSC_TEST_INPUTS && !core_idle) why = OSC_REASON_STATE;
    else if (needs_door(id) && !in->door_closed) why = OSC_REASON_DOOR;
    else if (moves_unit(id) && !in->bu_present) why = OSC_REASON_UNIT;
    else if (moves_unit(id) && in->brew_fault) why = OSC_REASON_DRIVER;
    else if (id == OSC_TEST_HEATER && in->boiler_dc == OSC_TEMP_INVALID) why = OSC_REASON_SENSOR;
    if (why == OSC_REASON_OK) {
        switch (id) {
        case OSC_TEST_PUMP:
            if (!param) param = 100; /* ml */
            if (param < 10 || param > 500) why = OSC_REASON_PARAM;
            break;
        case OSC_TEST_HEATER:
            if (!param) param = 90; /* degC */
            if (param < 40 || param > 105) why = OSC_REASON_PARAM;
            else if (in->boiler_dc >= (int16_t)(param * 10)) why = OSC_REASON_LIMIT;
            break;
        case OSC_TEST_GRINDER:
        case OSC_TEST_DOSE:
            if (!param) param = id == OSC_TEST_DOSE ? SVC_DOSE_GRIND_MS : 3000u; /* ms */
            if (param < 500 || param > OSC_GRINDER_MAX_ON_MS) why = OSC_REASON_PARAM;
            break;
        default:
            break;
        }
    }
    memset(s, 0, sizeof *s);
    s->r.id = id;
    s->param = param;
    s->t0 = s->t_step = now;
    s->edges0 = in->flow_edges;
    if (why != OSC_REASON_OK) {
        s->r.phase = OSC_TEST_REFUSED;
        s->r.reason = (uint8_t)why;
        return why;
    }
    s->r.phase = OSC_TEST_RUNNING;
    s->r.step = 1;
    return OSC_REASON_OK;
}

static void inputs_test(osc_service *s, const osc_inputs *in, uint32_t t) {
    int32_t *v = s->r.value;
    v[0] = in->door_closed;
    v[1] = in->bu_present;
    v[2] = in->bu_work;
    v[3] = in->water;
    v[4] = in->boiler_dc;
    v[5] = in->rail_24v_mv;
    if (t >= SVC_INPUTS_MS) finish(s, OSC_TEST_DONE, OSC_REASON_OK, s->t0 + t);
}

static void brew_test(osc_service *s, const osc_inputs *in, uint32_t now) {
    int32_t *v = s->r.value;
    const uint32_t ts = now - s->t_step;
    switch (s->r.step) {
    case 1: /* toward the work switch */
        s->out.brew_motor = true;
        s->out.brew_forward = true;
        if (ts < SVC_BREW_PEAK_MS) {
            if ((int32_t)in->brew_ma > s->peak) s->peak = in->brew_ma;
        } else {
            s->acc += in->brew_ma;
            s->n++;
        }
        if (in->bu_work) {
            v[0] = (int32_t)ts;
            v[1] = s->n ? s->acc / s->n : 0;
            v[2] = s->peak;
            v[3] = in->brew_ma;
            off(s);
            next(s, now);
        } else if (ts >= SVC_BREW_TIMEOUT_MS) {
            finish(s, OSC_TEST_ABORTED, OSC_REASON_TIMEOUT, now);
        }
        break;
    case 2: /* settle */
        if (ts >= 300u) next(s, now);
        break;
    case 3: /* back for as long as it took to get there */
        s->out.brew_motor = true;
        s->out.brew_forward = false;
        if (ts >= (uint32_t)v[0]) {
            v[4] = (int32_t)ts;
            finish(s, OSC_TEST_DONE, OSC_REASON_OK, now);
        }
        break;
    default:
        break;
    }
}

/* Relay or valve held for 'ms': 24 V before and in the middle of the run. */
static void hold_test(osc_service *s, const osc_inputs *in, uint32_t now, bool valve, uint32_t ms) {
    int32_t *v = s->r.value;
    const uint32_t t = now - s->t0;
    if (t == 0 || !v[0]) v[0] = in->rail_24v_mv;
    if (valve) s->out.valve = true;
    else s->out.mains = true;
    if (t >= ms / 2u && !v[1]) v[1] = in->rail_24v_mv;
    if (t >= ms) {
        v[2] = (int32_t)t;
        finish(s, OSC_TEST_DONE, OSC_REASON_OK, now);
    }
}

static int32_t pulses_to_ml10(int32_t pulses) {
    return (int32_t)((int64_t)pulses * 10000 / SVC_FLOW_PULSES_PER_L);
}

static void pump_test(osc_service *s, const osc_inputs *in, uint32_t now) {
    int32_t *v = s->r.value;
    const uint32_t ts = now - s->t_step;
    const int32_t pulses = (int32_t)(in->flow_edges - s->edges0);
    const int32_t target = (int32_t)((uint32_t)s->param * SVC_FLOW_PULSES_PER_L / 1000u);
    switch (s->r.step) {
    case 1: /* arm */
        s->out.mains = true;
        v[4] = in->boiler_dc;
        if (ts >= SVC_ARM_MS) {
            s->edges0 = in->flow_edges;
            next(s, now);
        }
        break;
    case 2: /* pump */
        s->out.mains = s->out.pump = true;
        v[0] = (int32_t)ts;
        v[1] = pulses;
        v[2] = pulses_to_ml10(pulses);
        v[3] = ts ? (int32_t)((int64_t)v[2] * 10000 / (int32_t)ts) : 0; /* ml/s x100 */
        v[5] = in->boiler_dc;
        if (pulses == 0 && ts >= SVC_PUMP_DRY_MS) finish(s, OSC_TEST_ABORTED, OSC_REASON_NO_FLOW, now);
        else if (pulses >= target || ts >= SVC_PUMP_MAX_MS) {
            s->out.pump = false;
            next(s, now);
        }
        break;
    case 3: /* release the relay after the pump */
        s->out.mains = true;
        if (ts >= SVC_ARM_MS) finish(s, OSC_TEST_DONE, OSC_REASON_OK, now);
        break;
    default:
        break;
    }
}
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

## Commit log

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2026-09-18 Validate front panel outline in KiCad 10.0.6
    Load the board in pcbnew (closed 10-vertex outline, four 8.4 mm holes,
    no footprint inside the board), run the front panel sync through KiCad
    Python and rerun DRC: the missing-outline error is gone and no new
    violation appears. Keep the pcbnew-normalized board ordering.
    [front-panel-reva.kicad_pcb]
2026-09-18 Lay out and route the front panel PCB for JLCPCB
    Assign JLC parts to the open positions: HRO K2-1102SP-A4SC-04 6x6x4.3 mm
    switches (C83916) with a project footprint from the EasyEDA land pattern,
    JST S8B-PH-K-S for J2 in the Waveshare cable order (C157915), and the
    standby LED on TCA9534 P7 (KT-0603R + 470R). Seven key channels replace
    the eighth, whose parts are removed from schematic and board.
    layout_front_panel_pcb.py places the parts on the measured positions,
    routes with Freerouting 2.4.1 through Specctra DSN/SES and pours GND on
    both layers with stitching and island anchoring. KiCad 10.0.6 DRC with
    schematic parity and all severities: 0 violations, 0 unconnected, 0
    parity issues. exp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
    [bom-draft.csv, front-panel-reva-bom-jlcpcb.csv, front-panel-reva.kicad_pcb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]
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2026-09-19 Enforce mains/SELV barrier and route STM32 supply
    Add a Mains net class and custom DRC rules: 8 mm clearance and creepage
    between primary copper and SELV, 2.5 mm between distinct mains tracks.
    The rule exposes 95 violations from the existing mains placement
    (F701/F702 beside the H-bridge, K701 in the logic area, J115 beside the
    12 V buck), so no mains copper is routed yet.
    Route the STM32 supply: VDD ring under the LQFP, one VSS via per pin,
    decoupling capacitors moved to their VDD/VSS pairs, and a provisional
    B.Cu GND_UI plane that the filler keeps 8 mm from mains copper.
    [controller-core-reva.kicad_pcb]
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2026-09-19 Switch to ESP32-S3-WROOM-1U and adopt the original board floorplan
    Replace U201 with ESP32-S3-WROOM-1U-N8R8 (JLCPCB C2980300): same pinout,
    U.FL connector for an external antenna. The WROOM-1 PCB-antenna keepout
    took about 1990 mm2, 10 % of the board, which the mains domain needs.
    Reorganise the board after the original: logic on top and left, an
    L-shaped 8 mm mains/SELV barrier, the mains domain in the lower centre
    and right, and the original 40 x 33 mm heatsink footprint reserved above
    JP8/JP19/JP24. K701 straddles the barrier; fuses and MOV sit above the
    heatsink; PS701 stands on the right edge with its AC pins beside J118.
    The STM32 block is placed and routed relative to U101, the USB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
    [bom-draft.csv, controller-core-reva.kicad_pcb, controller-core-reva.kicad_sch]
2026-09-19 Route mains input and 24 V output
    Mains: J118 phase to F701 and F702 to PS701 run nested down the gap
    beside PS701, 2.5 mm apart; the fused phase joins both fuse clips, RV701
    and the doubled K701 COM pads; neutral reaches PS701 on F.Cu and RV701 on
    B.Cu under both phases. Phase tracks are 3 mm on 1 oz, provisional until
    the heater stage sets the final copper.
    24 V: PS701 to J121, then a lane between the 3.3 V buck and the DRV8876
    resistors to J112 and the 12 V buck, and a trunk along the SELV edge of
    the barrier band to the brew branch, divider, J114, K701 coil, D701 and
    the valve branch. F701/F702 swap places, J121 is turned, C307 and Q701
    move to clear these routes.
    DRC with all severiti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
    [controller-core-reva.kicad_pcb]
2026-09-19 Double mains phase copper on both layers
    Owner decision: keep 1 oz copper, the cheapest JLCPCB option, and carry
    the ~10 A load current on 3 mm tracks duplicated on F.Cu and B.Cu with
    1.6/0.8 mm stitching vias (about 6 mm of 1 oz). L_IN is doubled up to
    y = 77 mm; the short F701 clip link stays on F.Cu where neutral crosses
    on B.Cu. The fused phase and the K701 NO pair are doubled throughout.
    DRC with all severities: 0 violations.
    [controller-core-reva.kicad_pcb]
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2026-09-19 Swap JP16 motor outputs and document the manual routing plan
    V1/V2 of JP16 now carry BREW_OUT2/BREW_OUT1 so both motor leads reach
    J108 uncrossed once the DRV8876 moves beside it. Record the Freerouting
    trial (kept as an experimental tool, not used by the build) and the
    agreed next steps: move the H-bridge next to JP16, J102/J103 to the top
    right, and route the remaining SELV blocks by hand.
    [controller-core-reva.kicad_pcb, controller-core-reva.kicad_sch]
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2026-09-20 Route the supervisor, interlocks and relay coil driver
    Tuck R601/R602 under U601 and flip U603 so its outputs face the gate
    resistors, keeping the 1.35 mm channel west of U601/U602 empty for STM_NRST.
    Route the 3V3 spine through U601, C601, U602 and C602, the watchdog kick
    chain, the valve arm pull-down, every ground pin on its own via, and the
    relay chain from U603 through R801/R802 and Q701 to the K701 coil and D701.
    Move the SWD and UART headers next to their chips: J102 above the STM32 and
    J103 beside the ESP32. DRC clean; 212 connections remain.
    [controller-core-reva.kicad_pcb]
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2026-09-20 Route the 12 V buck and document the routed blocks
    Route the switch node, output bank and divider chain of the AP63200 stage; the
    1210 output capacitors share a column with a ground pad, so the rail rounds
    them on the inner side. Leave the feedback leg from U303 pin 1 to R302 open and
    say why: the 24 V lane wraps round C310 to reach the input pins, leaving only
    the channel under the switcher, next to the switch node.
    Document every hand-routed block, the reserved reset channel, the back-layer
    hops under the power trunks, and two findings: U603 has no decoupling capacitor
    of its own, and the SN74LVC2G08 in the DCT package really does carry 2Y on pin
    3, which the generator's symbol already ma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
    [controller-core-reva.kicad_pcb]
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2026-09-20 Route the 3.3 V buck and the 12 V telemetry
    Move C302 under the switcher so the input loop closes across the package
    instead of reaching 8 mm to the bulk capacitor, and take the ground pin to the
    plane through that capacitor's own pad.
    Move the 24 V lane from x = 107.85 mm to the empty column at x = 112.5 mm. It
    used to climb between the inductor and the output capacitors, so every 3.3 V
    link crossed it; the capacitors now stay beside the inductor where they belong
    and J112 is fed by a short branch.
    Route 12V_FUSED over the diodes and 12V_PROTECTED under them, the switch and
    bootstrap nodes, the 3.3 V output bank, the sense line back to pin 1 round the
    north of the switcher, and the 12 V t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
    [controller-core-reva.kicad_pcb]
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2026-09-20 Distribute 3.3 V and ground the logic pins
    One line leaves the buck along y = 43 mm and splits. The northern branch climbs
    the gap between F301 and D301, runs over the ESP32 at y = 2.5 mm and feeds its
    supply pins, its strap resistors and the UART header, plus the STM32 reset
    pull-up and the SWD header. To free that gap, F301 moves 3 mm west and the
    fused 12 V link passes under D301's body on B.Cu instead of round it.
    The western branch runs in the 1.1 mm gap between the supervisor capacitors and
    the 24 V trunk, passing under two 24 V branches on B.Cu, and reaches the
    measurement header, the supervisor block, the arm gate and the contact and door
    pull-ups. R405 turns 270 degrees so its supp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
    [controller-core-reva.kicad_pcb]
2026-09-20 Route the reset tree
    R101 and C101 sat east of the STM32, but its reset is pin 7 on the west side,
    so the pair moves into the reset net's own corridor beside the supervisor that
    drives it. The pin leaves flat, because the west pads are on a 0.5 mm pitch and
    any diagonal touches its neighbour, drops to y = 50.5 mm and crosses west under
    both 24 V branches into the 1.35 mm channel that was left empty for it.
    Two reset points stay open and are documented: U602 pin 6, whose only approach
    is the 0.87 mm gap east of the package that the valve arm net already uses, and
    the SWD header's reset pin, which would have to cross the decoupling link north
    of the MCU. Neither blocks debugging or start-up.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
    [controller-core-reva.kicad_pcb]
2026-09-20 Route the service-USB rail
    VBUS runs from the connector to the sense divider, the resettable fuse and the
    bench-power jumper. The ESD part carries VBUS on the middle pin of its west
    side with the protected pair leaving on either side, so that pin is reached on
    B.Cu from the connector instead of through its own fanout. R202 turns 270
    degrees so its supply pad faces north and the ESP32 boot strap leaves below it
    without crossing.
    DRC clean; 75 connections remain.
    [controller-core-reva.kicad_pcb]
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2026-09-22 Place and route the heater stage on a 33 mm extruded heatsink
    Choose a standard extruded profile, 33 x 21 mm foot and 35 mm tall, at
    x = 62-95 mm. It stays at 33 mm rather than the original 40 because the
    switched phase has to get from K701 down to the triacs and the only way past is
    a 5 mm lane west of the profile. The foot now forbids copper as well as
    footprints, since the base sits on the board.
    Add the heater stage: MOC3083 straddling the barrier on the standard DIP land
    pattern (the long-pad one leaves 7.76 mm between rows, under the 8 mm rule),
    BTA24 against the heatsink, R710 in the lane, and an SI2308A driving the LED from
    12 V. The spare AND gate in U603 becomes the heater's reset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
    [bom-draft.csv, controller-core-reva.kicad_pcb, controller-core-reva.kicad_sch]
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2026-09-22 Route the heater interlock gate
    HEATER_EN_RAW now reaches U603 pin 5 and the R711 pull-down, and the
    gated output runs on B.Cu from pin 3 to R707. The reset loop around pin
    2 moves east to leave room for that via, and the relay enable runs
    straight west first so that pin 6 gets its reset through a via of its
    own. Only the PB10 leg from the MCU is left on this chain.
    [controller-core-reva.kicad_pcb]
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2026-09-22 Seat U701 on a slotted 300 mil footprint
    The catalogued MOC3083 (Lite-On, C10797) is the plain 7.62 mm DIP. The
    10.16 mm package the layout assumed is the MOC3083M, and JLC lists only
    three of those. Keep the stocked part and give it a footprint of its own,
    DIP-6_W7.62mm_BarrierSlot, with a 2 mm slot milled between the rows and
    3.5 mm past the end pins.
    The pads are 6.02 mm apart through air, but the surface path has to go
    round the slot and stays over 8 mm; with the slot removed, DRC reports
    6.02 mm of creepage. Only the air gap is relaxed, to 6 mm, and only for
    items wholly inside the 'optocoupler barrier slot' area: the pads and the
    short stubs that enter them. The barrier band now admit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
    [bom-draft.csv, controller-core-reva.kicad_pcb, controller-core-reva.kicad_sch]
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2026-09-22 Route the pump interlock gate
    Move U604 from the column west of MH2 to the free patch under Q701, U603's
    twin in the same orientation, where reset and 3.3 V are close. C604 and the
    R713 pull-down move with it. Only the gated output now has to run south to
    R714, as the heater's does.
    The pins leave by hand: raw order west to R713, reset north between the
    pad rows, 3.3 V east to C604, output east then south, grounds to their own
    vias. The long legs came from a grid search that favours F.Cu and are fixed
    in route_pump_enable. PB11 leaves U101's east side past the bottom-right
    decoupling, drops to B.Cu under the 24 V bend and runs west along the
    southern edge of the ground plane before climbing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
    [controller-core-reva.kicad_pcb]
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2026-09-22 Fit a top-entry USB-C for the service port
    With no height problem to worry about, the owner wants J110 vertical as
    well. HRO's TYPE-C-31-D-06 (C2689964, 3,265 in stock) is the same maker's
    16-contact USB 2.0 receptacle in a top-entry SMD body. KiCad has no such
    footprint, so OpenSaeco.pretty gets one from the recommended PCB layout
    of HRO's drawing (rev A, 2020-11-02). The LCSC/EasyEDA pattern it started
    from differed in two places: the signal pads are 0.87 mm long, 0.43 to
    1.30 mm from the centre line, and the east peg hole is a 0.72 x 0.52 mm
    slot, not a 0.72 mm round hole.
    The two contact rows face each other mirrored, 0.5 mm pitch, so the
    fanout is new. J110 sits at (36, 5), 5 mm in fro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
    [bom-draft.csv, controller-core-reva.kicad_pcb, controller-core-reva.kicad_sch]
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2026-09-23 Specify the grinder stage on an assumed 1 A
    The grinder's running current has not been measured. On the owner's call,
    Rev A assumes 1 A and the first prototype measures it (GR-01 to GR-06 in
    the characterization plan). The 68 ohm winding fixes the other two cases
    without measuring: at start and stall there is no back-EMF, so the current
    is 230/68 = 3.4 A RMS.
    The stage follows the original: a BTA24 (Q708) after K701 switches the
    phase, and a bridge after it gives JP8 fixed polarity and drops it the
    moment the triac opens. With no bus capacitor there is nothing to bleed.
    The opto is the heater's and pump's MOC3083 (U703): the grinder is only
    switched on and off, and the random-phase VOT8125A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
    [bom-draft.csv, controller-core-reva.kicad_sch]
2026-09-23 Place and route the grinder stage with its own fuse
    The mains area had no free spot for a third optocoupler and a free-standing
    TO-220, so the stage takes room from its neighbours. Three optocouplers now
    share the vertical barrier between K701 and J106 with 0.7 mm to spare:
    U701 moves up to y = 88, U703 goes in the middle and U702 stays. The three
    triacs share the heatsink's south face, grinder, heater and pump from west
    to east, which lets the heater gate run above the triac pins and the grinder
    gate below them without crossing. On the heatsink the grinder triac also
    rides out a stall.
    The owner chose a T2A fuse for the grinder: F703 is a JDT JFC2410-1200TS
    (C136382), time-lag, 250 V, on a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
    [bom-draft.csv, controller-core-reva.kicad_pcb, controller-core-reva.kicad_sch]
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2026-09-23 Route the load orders and the U602 outputs
    Every F.Cu path from the STM32 to the gates west of the 24 V trunk
    crosses the reset line, both 24 V branches and the 3.3 V spine; a per-net
    search needed 24 to 38 vias for the five nets. The four orders now run as
    one bus on B.Cu along the southern edge of the ground plane, two vias
    each, at the 0.4 mm pitch that fits between the 3.3 V hop vias and the
    barrier. North to south: pump, valve, grinder, heater, which is also the
    order in which they peel off west of the trunk.
    For that order to hold at the MCU end, GRINDER_EN_RAW moves from PB12 to
    PC4, beside PA7 in the south row. PA7, PC4 and PB10 drop into the pocket
    under U101 that the decoupling an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
    [controller-core-reva.kicad_pcb, controller-core-reva.kicad_sch]
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2026-09-23 Route the sensor inputs as one B.Cu bus and move the 24 V telemetry to PC1
    The sensor lanes leave U101 in the order of their filters, so the bus has
    no crossings and every net uses two vias:
    - PC3 water, PC2 group present, PA0 group at work, PA1 door,
    PA2 flow (TIM2_CH3), PA3 NTC (ADC1_IN4);
    - RAIL_24V_ADC moves from PA5 to PC1 (ADC2_IN7) and reaches J114.6 in
    7 mm, which removes the B.Cu lane that fenced the escape pocket.
    The brew sleep and watchdog climbs beside the supervisor move to In2.Cu
    so the bus crosses that column on B.Cu. Pin 12 no longer ties to C102
    by track; both reach the ground plane on their own vias.
    DRC 0 violations; 23 open connections, all ESP32 and front panel.
    Co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
    [controller-core-reva.kicad_pcb, controller-core-reva.kicad_sch]
2026-09-23 Route the ESP32 and front-panel signals; every net is now connected
    - R213-R218 move to one row under J104, at the cable entry, in the order
    the bus arrives: the LCD lines reach it without crossings, the four SPI
    lines as a parallel B.Cu bus with no vias beyond their ends.
    - ESP UART moves to east-side pins (TX IO17->IO42, RX IO18->IO2) beside
    R211/R212, so it no longer crosses under the module.
    - VBUS sense moves from IO21 to IO15, next to its divider; the 30 mm
    line under the module's south row is gone.
    - Keypad, EN, debug header and BOOT0 routed; nothing on F.Cu under the
    module and no via in a pad.
    DRC 0 violations and 0 unconnected items; parity differences are only
    the mounti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
    [controller-core-reva.kicad_pcb, controller-core-reva.kicad_sch]
2026-09-23 Drop the B.Cu hops that only crossed the old 3.3 V spine
    The UI supply's two hops, the UI enable hop at x = 91.6 mm and the
    heater enable hop under the former y = 67 mm branch now run on F.Cu,
    and the LCD reset line loses a redundant hop at the resistor row.
    274 vias (284 before); DRC 0 violations, 0 unconnected.
    [controller-core-reva.kicad_pcb]
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2026-09-23 Size the grinder for 3 A and double the load phase under the heatsink
    On the owner's call the grinder stage is sized for 3 A instead of an
    assumed 1 A running current. 3 A is not a credible running current with a
    68 ohm winding (it would burn about 610 W in the copper); it is an envelope
    close to the 3.4 A stall, so no part depends on the measurement any more.
    F703 becomes a JDT JFC2410-1400TS, T4A (C136386, 19,798 in stock), on the
    same footprint: 75 % loaded at 3 A. It no longer cuts a stall, which is the
    firmware's job. BR701 stays a KBP410: at 3 A it dissipates about 5 W, so it
    is rated for grinds of up to 10 s with a pause; a GBU does not fit between
    the barrier and JP19. The grinder tr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
    [bom-draft.csv, controller-core-reva.kicad_pcb, controller-core-reva.kicad_sch]
2026-09-23 Add ground fills, silkscreen, per-device mains rules, USB pair and TE FASTON tabs
    Fills: on the owner's delegation, F.Cu and B.Cu carry GND_UI over the whole
    SELV side, with the inner planes' outline, stitched to In1.Cu by 156 vias
    of 0.6 mm on a 5 mm grid wherever they clear copper, courtyards and
    keepouts. SMD pads join solid, through-hole pads with reliefs; one spoke is
    accepted on ground pads, which also meet the plane. 0.5 mm of clearance
    keeps the USB pair near its impedance. The mains side gets no fill.
    Silkscreen: a new script draws the owner's logo (traced from bicho.png),
    the title, every harness and service connector's original JP name and
    function, + and - on JP8, L and N on JP1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
    [bom-draft.csv, controller-core-reva.kicad_pcb, controller-core-reva.kicad_sch]
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2026-09-29 Bring the documentation in line with the routed board
    A full reread against the schematic, BOM, PCB and validation reports.
    Data errors: the flowmeter is on PA2 (TIM2_CH3) and the water level on
    PC3, not PA1/PA2; the ESP32 UART is on IO42/IO2 and VBUS sensing on IO15,
    not IO17/IO18/IO21; the brew current is read on PC0, not PA3; the ESP32
    code in the assembly notes is C2980300; the discarded VOT8125 row goes;
    the 27.5 ohm heater reading joins the measurement log.
    Stale state: footprint counts of 135 to 159, unrouted connections, a
    "partial schematic", undrawn mains stages and pending fills and
    silkscreen give way to the current 187-position routed board. The
    controller README, core-design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
    [connectors.csv, controller-core-reva.kicad_sch]
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2026-10-01 Straighten the controller routing to 45/90 degrees and shorten the detours
    - WATER_RAW drops to B.Cu under the valve return (42 -> 13 mm).
    - BU_WORK_RAW passes under the present-contact row on B.Cu (48 -> 21 mm).
    - The 12V_PROTECTED west leg runs down B.Cu at x = 16.75 mm instead of
    the left edge (105 mm and four vias -> 75 mm and two).
    - The STM_NRST via beside U603 no longer doubles back.
    - Off-angle segments over 0.3 mm drop from 206 to 50: corners at 45
    degrees, pad-to-via stubs squared by moving the via, five 0.25 mm jogs
    aligned and redundant collinear points removed. The rest are boxed in
    (USB VBUS by the keypad bus, pad entries, the mains side).
    Full DRC with schematic parit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
    [controller-core-reva.kicad_pcb]
2026-10-01 Fit the owner-identified Wurth WR-MM front-panel link on both boards
    The owner identified the connector of the original link between the main
    board and the front panel as Wurth WR-MM 690367181672 (16 contacts at
    1.27 mm stagger), the same part at both ends of a 1:1 16-wire flat cable.
    The latch of the cable plug enters a 1.5 mm hole beside pin 1, which locks
    it and sets its direction, so pin 1 always meets pin 1. It replaces the
    2x8 IDC in J104 and J1. JLCPCB lists it as C19103863, without stock.
    The footprint follows Wurth drawing 690367181672 rev 002.000: 0.85 mm
    holes, 1.4 mm pads, a 22.32 x 5 mm body and the 1.5 mm non-plated latch
    hole; it gets a 6.1 mm tall stand-in model shared by bo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
    [bom-draft.csv, connectors.csv, controller-core-reva.kicad_pcb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]
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2026-10-01 Add the board model for the firmware simulator and fix what it found
    F0 of the simulator: tools/build_board_model.py joins both KiCad netlists
    through the J104/J1 harness and checks them against a firmware contract
    (firmware/common/signals.json) and vendor pinouts (sim/reference/). It
    resolves every firmware signal to its physical pad, peripheral, AF and ADC
    channel, traces each order to its load and through the watchdog AND gate,
    solves the reset levels and the analog inputs by nodal analysis, and
    checks the harness and the TCA9534 keypad. It generates board_pins.h for
    both MCUs, sim/board-model.json for F1 and sim/board-report.md. Stdlib
    only; 20 mutation tests in tests/sim and a C test of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
    [bom-draft.csv, connectors.csv, controller-core-reva.kicad_pcb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]
2026-10-05 Add F1 of the simulator and drive the relay and opto MOSFETs from 3.3 V
    F1: sim/osc_sim/circuit.py solves both boards as a switch-level DC
    network built from the netlists, with the guaranteed limits of every
    active part in sim/reference/devices.json (datasheet per part). The new
    'drive' rule (sim/osc_sim/drive.py) requires every order to move its load
    at both ends of the rails: active, inactive, with the MCU in reset and,
    when interlocked, with STM_NRST low and the pin still driven. Anything
    between two guaranteed points is undefined and fails. The report gains a
    worst-case margin table.
    The STM32 gets osc_hal.h, a BSP and a main loop (WDI every 100 ms). The
    firmware is built for the host o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
    [bom-draft.csv, controller-core-reva.kicad_pcb, controller-core-reva.kicad_sch]
2026-10-05 Square STM_NRST with a Schmitt buffer for the interlock gates
    The new slow-edge rule of the simulator (sim/osc_sim/drive.py) checks that
    logic inputs without hysteresis do not hang on a slow RC. It found the six
    reset inputs of U602-U604 (SN74LVC2G08) on STM_NRST, which rises through
    R101 (10k, with the STM32's own pull-up) into C101 (100 nF): about
    530 us/V, where TI SCES198N allows 10 ns/V at 3.3 V. With an order active,
    the falling edge of a watchdog reset could make a gate output oscillate
    before it settles low. No Schmitt-input equivalent fits the SM-8 footprint.
    U605, an SN74LVC1G17DBVR (TI, C7836) with C605 = 100 nF, takes STM_NRST
    and drives STM_NRST_BUF to the six inputs (VT+ 1.92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
    [bom-draft.csv, controller-core-reva.kicad_pcb, controller-core-reva.kicad_sch]
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
